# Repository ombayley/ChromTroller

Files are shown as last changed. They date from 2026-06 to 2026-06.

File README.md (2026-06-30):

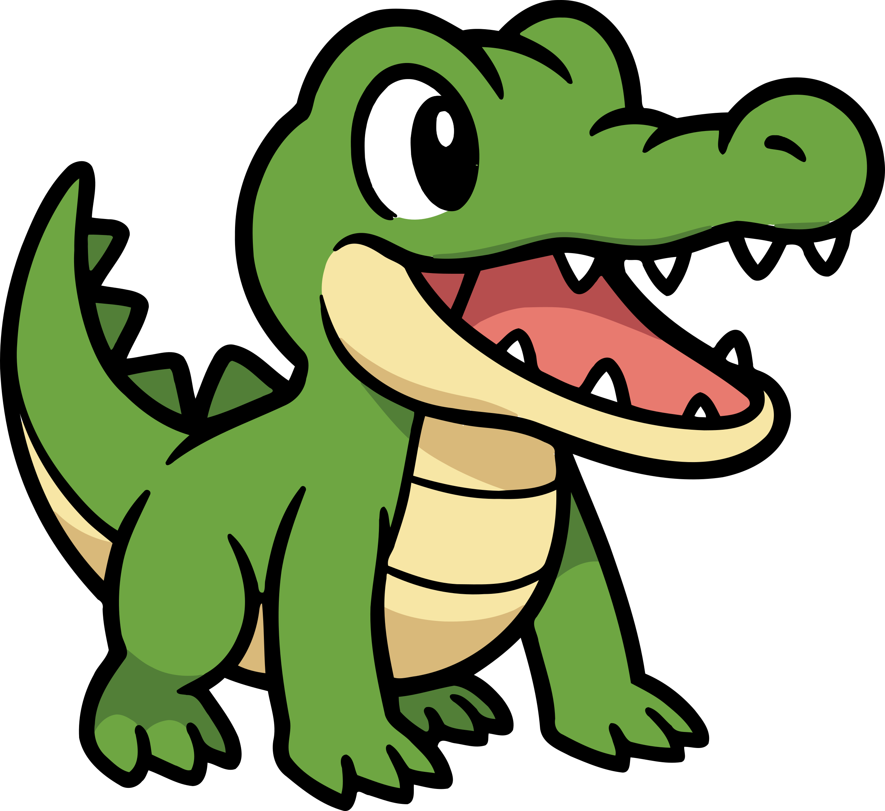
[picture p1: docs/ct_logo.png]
#  ChromTroller

> ***"Pressure makes diamonds"***  
> — *George S. Patton Jr.*
---

## 🧪 Overview
**ChromTroller** (Chromatogram Acquisition Controller) is an automated control‑and‑analysis package that triggers an **Agilent 1290 Infinity II UPLC‑MS** via an **Arduino** and automatically analyzes the resulting chromatographic data.  
It integrates LC/MS hardware (valves, sensors) with a remoteable client–server app and a robust analysis pipeline (MOCCA‑based), making it easy to slot an Agilent UPLC into automated workflows.

ChromTroller was developed to bridge **OpenLab CDS v2.8** (which lacks macro automation) with external experiment controllers (e.g., **RoboChem**) by providing **hardware control**, **data analysis**, and **TCP/IP communication** between PCs.

---

## 📋 Table of Contents

- [Installation](#️installation)
  - [Dependencies](#-dependencies)
  - [Environment Setup](#-environment-setup)
  - [Hardware & Firmware](#-hardware--firmware)
- [Usage](#️usage)
  - [Prepare](#prepare)
  - [Start the Server](#start-the-server)
  - [Configure Settings](#configure-settings)
- [HPLC System Details](#-uplc-system-details)
- [Automation & Connectivity](#-automation--connectivity)
- [Project Structure](#-project-structure-simplified)
- [Architecture](#-architecture)
- [Troubleshooting](#-troubleshooting)
- [Contributing](#contributing)
- [License](#license)
- [Acknowledgements](#acknowledgements)
- [Author](#author)

---

## ⚙️ Installation

### 📦 Dependencies
Before proceeding, make sure you have:

- [**Python 3.8+**](https://www.python.org/downloads/) *(Recommended: Python 3.13)*
- [**Conda**](https://www.anaconda.com/download) *(Recommended: install via Anaconda)*
- [**Git**](https://git-scm.com/downloads)
- **Arduino IDE** from [arduino.cc](https://www.arduino.cc/)
- **Agilent OpenLab CDS v2.8** (instrument control)
- *(Optional)* A Python IDE (e.g. [**PyCharm Community Edition**](https://www.jetbrains.com/pycharm/download/?section=windows))

*Conda helps isolate project dependencies to avoid version conflicts across Python projects.  
Git enables version control and easy updates to the codebase.*

---

### 🧪 Environment Setup
Create and activate the Conda environment from the provided spec:

```bash
conda env create -f .config/ChromTroller_env.yml
conda activate ChromTroller
```

---

### 🧠 Hardware & Firmware
1) **Assemble & wire hardware**  
   Follow the **control box** assembly guide in [`assembly_readme.md`](assembly_readme.md).

2) **Upload the Arduino sketch**  
   - Board: **Arduino Uno R3**  
   - Connect via USB and select the correct **COM** port in the Arduino IDE.  
   - Upload the firmware from `src/arduino_sketches/`.

3) **Supported peripherals**  
   - **VICI** two‑position six‑port switch valve (with micro‑electric actuator & controller)  
   - **OCB350** phase sensor board  
   - Agilent **1290 Infinity II UPLC‑MS**

---

# ▶️ Usage

### Prepare
- Ensure **OpenLab CDS v2.8** is installed and the instrument is available on the **instrument PC**.
- Connect the **Arduino Uno R3** over USB; note the assigned **COM** port.
- Verify valves and sensors are wired and powered.
- Confirm file paths (raw data, results) are accessible by the account running ChromTroller.

### Start the Server
Launch the ChromTroller server on the instrument PC:

```bash
python ChromTroller.py
```

This exposes a **TCP/IP socket** for remote clients (e.g., RoboChem) while handling low‑level device control and data analysis.

### Configure Settings
Copy the example settings and customize for your setup:

```text
src/settings_files/example_settings.json  →  src/settings_files/settings.json
```

Key fields to adjust:
- **Hardware**: Arduino **COM** port, valve positions, timeouts  
- **Analysis**: Peak detection/integration parameters, baseline correction, wavelength ranges  
- **Paths**: Project directories, file naming, raw data / results locations  
- **Targets**: Retention times and tolerances for peak assignment

---

## 🔬 UPLC System Details

**Instrument:** Agilent 1290 Infinity II series with:  
- **High Speed Binary Pump** (G7120A)  
- **Vial Sampler** (G7129B)  
- **Thermostated Column Compartment** (G7116B)  
- **Diode Array Detector** (G7117B, DAD)  
- **InfinityLab LC/MSD XT** Single Quadrupole detector (G6135C)

**Injection hardware:** External **VICI** two‑position six‑port valve with a **1.0 µL** stainless‑steel loop (≈ 90 mm × 0.12 mm). Effective injected volume ≈ **1.4 µL** due to additional valve dead volume.

---

## 🔗 Automation & Connectivity

**OpenLab CDS v2.8** controls the UPLC but lacks a macro language for automation. **ChromTroller** fills this gap by providing:

1. **Hardware control** (valve actuation, ERI digital I/O, phase sensor).  
2. **Data analysis** (see next section).  
3. **Intersystem communication** (TCP/IP sockets).

### Sample Injection & Triggering
- A VICI valve is installed **between the vial sampler and column**.  
- **Position “load”** fills the loop from the external process at low pressure; **position “inject”** places the loop inline for analysis.  
- The **VICI actuator** is driven from the control box; the **UPLC acquisition** is triggered via **Agilent ERI** digital input.  
- In OpenLab, a **Sample Prep** method is configured to **wait for an external trigger** (e.g., “pin 1”). Runs can be queued and started only when the **START REQUEST** signal is received from ChromTroller/Arduino.

This ensures **tight timing** between valve switching and acquisition start, improving retention‑time reproducibility and peak shapes.

### Serial Protocol (to Control Box)
Commands are human‑readable:
- **Set:** `Sx=y` (no response unless specified)
- **Read:** `Rx` (always returns value)

Key variables include: valve position (`5`, 0=A / 1=B), **START REQUEST** (`6`), **STOP** (`7`), **READY** (`8`), **phase sensor** (`9–10`), and ERI **state lines** (`11–13`). See [`assembly_readme.md`](assembly_readme.md) for the full table.

---

## 🧠 Data Analysis

ChromTroller includes a processing pipeline based on the [**MOCCA**](https://github.com/Bayer-Group/MOCCA) package from the BAYER group.
This analysis system parses the raw files, automatically processes the chromatograms contained within , and returns tidy results (e.g., a pandas DataFrame). Operations include:
- file parsing and dimensional reduction  
- baselining and peak picking  
- deconvolution, integration, and quantification  
- identity assignment and error analysis

This enables multi‑wavelength chromatograms to be consumed by external platforms (e.g., RoboChem) as simple peak integrals.

---

## 📂 Project Structure (Simplified)

```
ChromTroller/
├── .config/                 # Conda environment specs
├── docs/                    # Documentation & diagrams
├── reference_spectra/       # Reference spectra for analysis
├── reference_spectra_db/    # Spectra database
├── results/                 # Latest analysis results
├── run_logs/                # Runtime logs
├── saved_results/           # Archived analysis runs
├── src/                     # Source code
│   ├── ct_components/       # Core components
│   │   ├── devices/         # Device interfaces
│   │   └── mocca2/          # MOCCA-based analysis
│   ├── arduino_sketches/    # Arduino firmware
│   └── settings_files/      # JSON configuration
├── ChromTroller.py          # Entry point (server)
├── assembly_readme.md       # Control box build guide
└── README.md
```

---

## 🧱 Architecture

```mermaid
graph TD;
    Client[Client Application] <-->|TCP/IP Socket| Server[ChromTroller Server]
    Server <--> Controller[LCMS Controller]
    Controller <-->|Serial| Arduino[Control Box]
    Arduino -->|I/O| LCMS[Agilent LC/MS]
    Arduino -->|I/O| Valve[VICI Switch Valve]
    Controller --> Monitor[System Monitor]
    Controller --> Analyzer[Data Analyzer]
```

---

## 🛠️ Troubleshooting

**Connection issues**
- Confirm the **COM** port in `settings.json` matches Device Manager.
- Ensure **Arduino drivers** are installed and the board is detected.
- Close any program using the serial port (Arduino Serial Monitor, etc.).

**Acquisition/trigger issues**
- Verify the OpenLab **Sample Prep** method waits for the correct **ERI pin**.
- Check grounds/common reference between ERI and control box.
- Confirm valve position changes acknowledge back to the host.

**Analysis errors**
- Verify raw data paths and filenames match LC/MS export settings.
- Check analysis parameters (peak detection, baselining) against your method.
- Ensure **reference spectra** exist and are correctly formatted.

---

## Contributing
Contributions are welcome—please open a Pull Request with a clear description of your changes.

---

## License
This project is licensed under the **GNU General Public License (GPL)**. See the `LICENSE` file for details.
The GPL License is a copyleft license, that requires any derivative work to also be released under the GPL License.
This means any derivative software that uses this code remains open-source and freely available to the public.

---

## Acknowledgements
- **Bayer Group** for the **MOCCA** package
- **Agilent Technologies** for instrument support

---

## Author
**Olly Bayley** — *Noël Research Group, 2024* — <o.m.bayley@uva.nl>

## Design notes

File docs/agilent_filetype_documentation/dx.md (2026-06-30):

.dx files have been introduced in the latest version of Agilent's OpenLab CDS software and have no official documentation fo rhtier build.
These files are compressed archives and can be extracted with pythons zipfile module.
within these files are:
```
MSData/MSScan.xsd
_rels/.rels
[Content_Types].xml
MSData/Contents.xml
MSData/Devices.xml
2d4ed283-e283-470a-985f-c8650b5b92ba.UV
2d4ed283-e283-470a-985f-c8650b5b92ba.UVD
_rels/2d4ed283-e283-470a-985f-c8650b5b92ba.UV.rels
1aff4f0e-4b5d-4e62-a6b1-08e206e7c1a8.IT
...
4bf708a6-c0b3-4d70-87d3-de375632a9f9.IT
a94b341b-8600-47a2-aad6-641f0e04fb1f.CH
742c0a8e-994d-4588-a6a1-122438f1cbba.grd
2ce53aef-85cd-485f-84b8-cc1849d7ffb5.grd
MSData/MSTS.xml
injection.acmd

```

the .xml and .xsd files contain metdatadata on the aquired MS data which is stored seperately in the .MSPeak.bin and .MSScan.bin files.
the .UV files contain the 3D UV data of the chromatogram across wavelengths.
the .UVD files contain UV data of the chromatogram at a given wavelength.
the .IT files contain all the info of the hardware (temperatures, currents, pressures, etc...) but are not marked

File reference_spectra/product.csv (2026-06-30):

Wavelength | Absorbance
190 | 1774.6708765626
192 | 2121.88488990068
194 | 2375.61110407114
196 | 2525.90990811586
198 | 2598.21579605341
200 | 2442.80843436718
202 | 2021.09553664923
204 | 1645.53967863321
206 | 1429.40447479486
208 | 1363.24195563793
210 | 1403.28350663185
212 | 1500.91804563999
214 | 1630.83799928427
216 | 1786.28665208817
218 | 1962.86478638649
220 | 2138.08164000511
222 | 2239.62888866663
224 | 2217.36065298319
226 | 2048.58722537756
228 | 1695.46644389629
230 | 1189.98455256224
232 | 750.307559967041
234 | 438.227631151676
236 | 237.149432301521
238 | 127.045348286629
240 | 70.9682479500771
242 | 48.0436086654663
244 | 40.6952500343323
246 | 41.3642153143883
248 | 46.7967465519905
250 | 55.819496512413
252 | 68.8679218292236
254 | 85.2684676647186
256 | 106.099911034107
258 | 131.305046379566
260 | 159.867562353611
262 | 192.783609032631
264 | 229.336336255074
266 | 267.788626253605
268 | 307.406671345234
270 | 344.527617096901
272 | 379.161648452282
274 | 408.477559685707
276 | 419.78008300066
278 | 404.235295951366
280 | 376.990087330341
282 | 346.709810197353
284 | 287.109293043613
286 | 192.304745316505
288 | 103.096276521683
290 | 46.9016432762146
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

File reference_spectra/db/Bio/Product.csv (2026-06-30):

wavelength | absorbance
200.11 | 1652248.317841719
201.35 | 1518626.7446007319
202.59 | 1409723.0336609771
203.83 | 1345719.0684464027
205.07 | 1315815.34410467
206.32 | 1335642.3990441423
207.56 | 1374566.634268652
208.8 | 1386294.327582356
210.04 | 1355498.8827266581
211.29 | 1222791.7088032707
212.53 | 1013564.1721269303
213.77 | 807294.566148546
215.02 | 659859.0798216447
216.26 | 576460.3337595625
217.51 | 544372.7893987078
218.75 | 547171.3919146114
220.0 | 573304.3286487326
221.24 | 618176.3197648147
222.49 | 681218.3270397268
223.73 | 762177.7880653779
224.98 | 859045.5369520837
226.23 | 972766.143825681
227.47 | 1102406.9129294488
228.72 | 1246440.3125703991
229.97 | 1406488.0750157111
231.21 | 1577238.971505137
232.46 | 1768913.1941411793
233.71 | 1986559.759761608
234.96 | 2249590.8561227727
236.21 | 2642367.3698617904
237.46 | 3602018.0435978174
238.7 | 3995753.818190497
239.95 | 3997355.226358936
241.2 | 3998559.2014973755
242.45 | 3999506.0577509594
243.7 | 4000112.0859490363
244.95 | 4000691.566861483
246.2 | 4001020.8119115396
247.45 | 3101606.0585562405
248.7 | 2536995.9973240388
249.96 | 2274294.6582513503
251.21 | 2089659.7870108662
252.46 | 1948915.9306409345
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

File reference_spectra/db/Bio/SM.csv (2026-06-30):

wavelength | absorbance
200.11 | 1600300.5390176924
201.35 | 1467923.8272445255
202.59 | 1358122.9078490594
203.83 | 1264765.0566162318
205.07 | 1198447.4764689966
206.32 | 1148110.328346475
207.56 | 1103487.1848139924
208.8 | 1047433.1408762458
210.04 | 980121.6066031756
211.29 | 904700.4083839374
212.53 | 830516.1944663429
213.77 | 764927.9947905622
215.02 | 709102.8668123287
216.26 | 663878.5572056993
217.51 | 626569.1597787745
218.75 | 593176.0468914836
220.0 | 563295.510730236
221.24 | 535586.7281283623
222.49 | 510241.09102563275
223.73 | 489444.80710435455
224.98 | 474612.7214355952
226.23 | 466878.62356072484
227.47 | 466052.06095353345
228.72 | 472449.9139672729
229.97 | 484896.51980854647
231.21 | 503562.3369430287
232.46 | 528277.3686688787
233.71 | 559442.2327329945
234.96 | 597356.5471626982
236.21 | 642226.5448825333
237.46 | 695181.5851742572
238.7 | 757515.7183649899
239.95 | 829415.5770351929
241.2 | 911014.2212274143
242.45 | 1000763.6215320051
243.7 | 1097315.8393677927
244.95 | 1198720.1136332257
246.2 | 1301654.7210051392
247.45 | 1404777.2871813453
248.7 | 1505385.9711170834
249.96 | 1601488.9095195592
251.21 | 1690701.1976298431
252.46 | 1772766.4592760615
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

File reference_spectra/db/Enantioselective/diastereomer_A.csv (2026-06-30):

wavelength | absorbance
220 | 32929570.901172925
221 | 30251595.791809924
222 | 27583494.818783533
223 | 24920838.862576447
224 | 22281363.59773891
225 | 19708573.553817563
226 | 17133784.992652226
227 | 14899457.244885486
228 | 12923490.142887829
229 | 11244676.08669167
230 | 9881621.35323525
231 | 8785643.164572146
232 | 8050352.479092054
233 | 7579730.6301938
234 | 7338509.315241723
235 | 7293871.174475303
236 | 7420382.117641768
237 | 7687797.818173384
238 | 8076449.919397999
239 | 8601397.975483036
240 | 9191594.24214197
241 | 9852788.080277443
242 | 10609693.603409687
243 | 11362795.19895376
244 | 12133063.595042046
245 | 12906321.155902734
246 | 13710361.519871686
247 | 14441107.555550737
248 | 15116374.461307991
249 | 15736769.00143304
250 | 16205210.952189613
251 | 16533867.067726329
252 | 16719365.25556228
253 | 16747056.601230377
254 | 16642112.627814714
255 | 16402371.820754118
256 | 16056131.942559408
257 | 15541650.596207984
258 | 14871824.327734014
259 | 13980749.864755994
260 | 12775419.005677002
261 | 11405935.32215776
262 | 9892922.952019326
263 | 8259552.939423117
264 | 6790920.935680518
265 | 5414517.3507355
266 | 4314561.486903784
267 | 3374841.152450751
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

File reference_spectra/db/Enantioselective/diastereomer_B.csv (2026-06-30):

wavelength | absorbance
220 | 146213297.49883443
221 | 133537360.24735336
222 | 121009732.8859455
223 | 108921893.9741113
224 | 97455809.49136508
225 | 86720889.4986895
226 | 76273984.969608
227 | 67300330.93427262
228 | 59308084.82672971
229 | 52365329.69812251
230 | 46520327.205076724
231 | 41572457.86271553
232 | 38014100.236981496
233 | 35493444.15485315
234 | 33922945.50170027
235 | 33182879.313989375
236 | 33248012.0135607
237 | 33972025.61092472
238 | 35281486.149522275
239 | 37231809.69035273
240 | 39559161.97460105
241 | 42280367.271799624
242 | 45509599.48347034
243 | 48818600.777864635
244 | 52293686.93691794
245 | 55869603.75952901
246 | 59694385.30479761
247 | 63301515.31915083
248 | 66795605.77397436
249 | 70212349.72042921
250 | 73009906.00948425
251 | 75197434.31494759
252 | 76714577.76822823
253 | 77377584.36839387
254 | 77344139.10675211
255 | 76682552.50434124
256 | 75537485.23177217
257 | 73702112.31727603
258 | 71129598.20131448
259 | 67416444.14116977
260 | 62026025.24018093
261 | 55614213.38144096
262 | 48340234.38580763
263 | 40372242.82207139
264 | 33161537.512689497
265 | 26366671.987668518
266 | 20905616.22336069
267 | 16223439.586571513
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

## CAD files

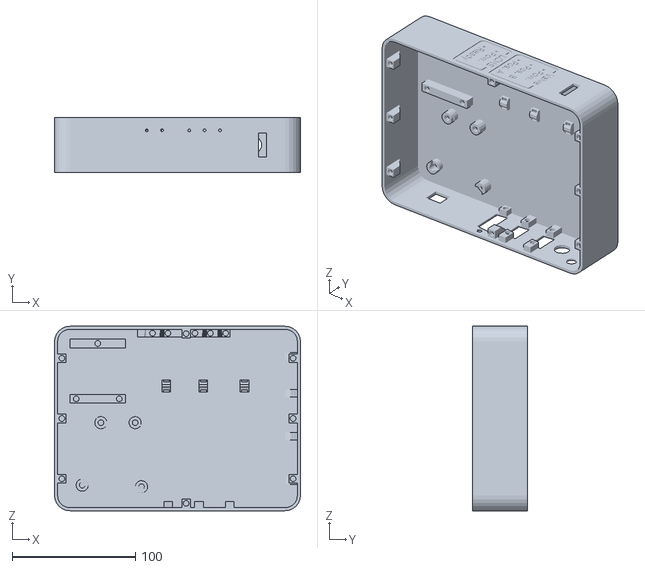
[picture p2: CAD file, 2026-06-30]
src/hrd_control/devices/arduino_controller/stl/LC_ENC.stl
200.0 x 45.0 x 150.0

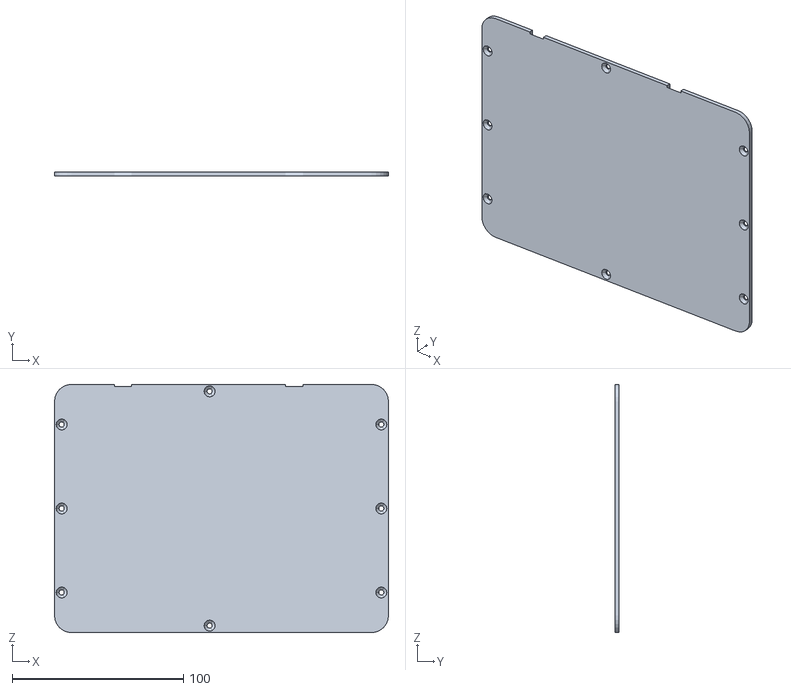
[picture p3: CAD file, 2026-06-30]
src/hrd_control/devices/arduino_controller/stl/LC_ENCL.stl
194.9 x 2.50 x 144.9

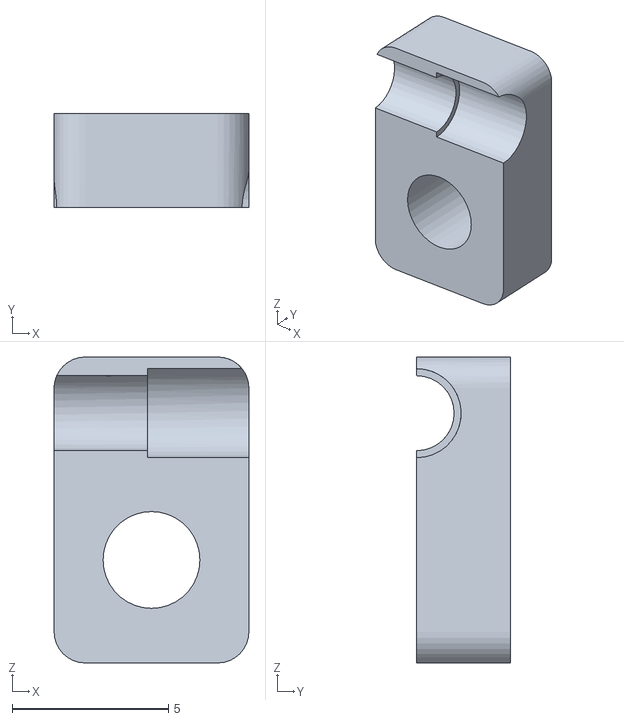
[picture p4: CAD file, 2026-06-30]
src/hrd_control/devices/arduino_controller/stl/LED_clamp.stl
6.24 x 3.00 x 9.80

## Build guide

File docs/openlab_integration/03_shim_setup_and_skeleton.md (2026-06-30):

# OpenLab Shim: Setup, Concepts, and Skeleton

This guide gets you from nothing to a running **C# shim** that drives the Agilent 1290 via
the OpenLab Acquisition SDK, controlled from ChromTroller's normal **64-bit Python**. It
covers environment setup, how the pieces fit together, and the full skeleton code.

**The skeleton files (all the code) live alongside this guide:**

```
docs/openlab_integration/shim/
  OpenLabShim/
    OpenLabShim.csproj      # x86 / net48 build definition + SDK references
    Program.cs              # the shim: connect, take control, dispatch loop, events
    shim.config.json        # discovered values (IDs, valve firmware cmds, param map)
  python/
    openlab_device.py       # CT-side client (default + whitelist policy lives here)
    example_usage.py        # minimal end-to-end demo
```

- C# shim: [Program.cs](shim/OpenLabShim/Program.cs), [OpenLabShim.csproj](shim/OpenLabShim/OpenLabShim.csproj), [shim.config.json](shim/OpenLabShim/shim.config.json)
- Python client: [openlab_device.py](shim/python/openlab_device.py), [example_usage.py](shim/python/example_usage.py)

---

## 1. How it works (conceptually)

```
RoboChem client ──TCP──► ChromTroller (64-bit Python)
                            │  stdin/stdout line protocol
                            ▼
                       OpenLabShim.exe (x86 .NET 4.8)  ← the ONLY 32-bit component
                            │  in-process SDK calls
                            ▼
                       OpenLab Acquisition ──► 1290 Infinity II
```

**Why a separate process at all.** The OpenLab Acquisition assemblies are **x86 /
.NET Framework**. Loading them *in-process* would force ChromTroller itself to be 32-bit
(breaking MOCCA/numpy). Putting them in a **separate process** decouples bitness: a 64-bit
and a 32-bit process coexist fine and just exchange text. The shim is the same architectural
role the Arduino plays today — an out-of-process device CT talks to over a line protocol —
only it calls the real SDK instead of toggling pins.

**Why it's persistent.** Connecting to the instrument is a slow, stateful handshake
(authenticate → `EstablishConnection` → wait for `AppInitialized` + `InstrumentStateChange`)
and run progress arrives as **events**. So the shim connects **once** at startup, takes
control, then loops reading commands. One process, many commands — exactly like opening a
serial port once.

**Two output channels on one pipe.** Every command gets a synchronous `OK ...` / `ERR ...`
reply. Run progress is *unsolicited*: `EVENT ...` lines during the run and a final
`RESULT <id> <path>`. The Python client's reader thread classifies the two — replies go to a
response queue the command call blocks on; events go to a callback CT uses to stream status
and detect completion.

**Where policy lives.** ChromTroller owns the *policy* — the method library, defaults, which
overrides are allowed and their ranges (the `default + whitelist` design). The shim owns the
*SDK mapping* — module hashkeys, the valve's firmware string, which property id a logical
param maps to. The client only ever uses logical names; instrument internals never leak out.

---

## 2. The line protocol

| Direction | Message | Meaning |
|---|---|---|
| CT → shim | `PING` | liveness check → `OK pong` |
| CT → shim | `SET_VALVE load` / `SET_VALVE inject` | switch built-in valve (firmware command) |
| CT → shim | `SET_PARAM flow=0.5` | stage a whitelisted deep method override |
| CT → shim | `START_RUN {json}` | submit a run (json: method, processing, vial, injvol, result) |
| CT → shim | `ABORT` | abort current run |
| CT → shim | `STATUS` | current instrument state |
| CT → shim | `QUIT` | disconnect and exit |
| shim → CT | `READY` | connected + control taken (emitted once at startup) |
| shim → CT | `OK <payload>` / `ERR <msg>` | synchronous reply to the last command |
| shim → CT | `EVENT STATE <state>` / `EVENT RUN <id> <status>` | async progress |
| shim → CT | `RESULT <id> <path>` | run complete; `.dx` result path |
| shim → CT | `FATAL <msg>` | startup/connection failure |

`START_RUN` uses a JSON payload (not space-delimited tokens) so method paths with spaces
escape cleanly.

---

## 3. Environment setup

### 3.1 Prerequisites (on the Acquisition PC / AIC)

- [ ] OpenLab CDS 2.8 **Acquisition** installed; the 1290 is configured and controllable
      from the OpenLab UI.
- [ ] **OpenLab SDK entitlement licensed** (Control Panel → Administration → Licenses).
      Without it `EstablishConnection` fails.
- [ ] You can read the **Instrument GUID** and **Project GUID** from the OpenLab Control
      Panel (used in `shim.config.json`).
- [ ] A service account (login/domain/password) the shim authenticates as.
- [ ] **Bench-discovery values** to fill the config: the column-valve firmware commands for
      each position, and the module-name/property-id for any deep params you expose
      (`flow`, `col_temp`). These come from the discovery script (next deliverable) / Lab
      Advisor — do not guess them.

### 3.2 C# build environment

- Install **Visual Studio 2022** with the **.NET desktop development** workload, *or* the
  **.NET Framework 4.8 Developer Pack** + .NET SDK (for `dotnet build`).
- The project targets **`net48`** and **`PlatformTarget=x86`** — both are mandatory and
  already set in [OpenLabShim.csproj](shim/OpenLabShim/OpenLabShim.csproj).
- Fix the assembly `HintPath`s in the csproj to match your install:
  - The two `Agilent.OpenLAB.Acquisition.*` assemblies are in the **32-bit GAC**. List the
    folder to get the exact version segment:
    ```bat
    dir "C:\Windows\Microsoft.NET\assembly\GAC_32\Agilent.OpenLAB.Acquisition.AutomationInstrument"
    ```
  - `Agilent.OpenLab.SharedServices*` are under
    `C:\Program Files (x86)\Agilent Technologies\OpenLab Services\Common\` and
    `...\OpenLab Acquisition\`.
- Build (x86):
  ```bat
  dotnet build docs\openlab_integration\shim\OpenLabShim\OpenLabShim.csproj -c Release
  ```
  or build the project in Visual Studio with the **x86** configuration. Output:
  `OpenLabShim.exe`.

> The build does **not** copy the Agilent DLLs locally (`<Private>false</Private>`). At
> runtime they (and their many dependencies) are resolved from the install dirs by the
> `AssemblyResolve` handler in `Program.cs`. Keep the exe on the AIC where those dirs exist.

### 3.3 Python environment

**No new environment.** This is the whole point — ChromTroller's existing **64-bit** env is
untouched. There is no pythonnet, no 32-bit Python, no second conda env.

1. Copy [openlab_device.py](shim/python/openlab_device.py) into
   `src/hrd_control/devices/` when you integrate (it has no third-party dependencies —
   stdlib only).
2. Edit the **policy block** at the top of `openlab_device.py` — `METHODS`, `DEFAULTS`,
   `OVERRIDE_WHITELIST`, `PARAM_WHITELIST` — to match your methods and the knobs you want
   the client to control. Keep the `PARAM_WHITELIST` keys in sync with the shim config's
   `ParamMap`.

### 3.4 Configure the shim

Edit [shim.config.json](shim/OpenLabShim/shim.config.json):

- `Login` / `Domain` / `Password` — the service account. **Do not commit a real password**;
  inject it at deploy time from a secret.
- `InstrumentId` / `ProjectId` — GUIDs from Control Panel.
- `ValveModuleMatch` — a substring of the column-compartment module name (e.g. `"Column Comp"`).
- `ValveFirmware.load` / `.inject` — the discovered firmware command strings.
- `ParamMap` — for each whitelisted deep param, the module-name substring + resource
  property id from discovery.

---

## 4. First run / smoke test

1. Build the shim (§3.2) and fill the config (§3.4).
2. Quick manual check straight from a terminal (type commands, watch replies):
   ```bat
   OpenLabShim.exe shim.config.json
   READY
   PING
   OK pong
   STATUS
   OK Idle
   QUIT
   OK bye
   ```
   If you see `FATAL ...` instead of `READY`, the connection failed — check the SDK
   license, the GUIDs, and that you're on the AIC.
3. End-to-end from Python: edit the paths at the bottom of
   [example_usage.py](shim/python/example_usage.py) and run it in your 64-bit env.
   It does: `set_valve("load")` → `submit_run(...)` → waits for the `RESULT` event.

---

## 5. Integrating into ChromTroller

The shim/client mirror the existing device abstraction, so integration is mostly swapping
the transport:

- Add `src/hrd_control/devices/openlab_device.py` (the client).
- In [ct_controller.py](../../src/hrd_control/ct_controller.py):
  - construct `OpenLabDevice(exe, config, on_event=...)` and `start()` it where the
    Arduino/`LCMSDevice` is set up today;
  - `run_sample_acquisition()` becomes: `set_valve("load")` → (await loop fill) →
    `submit_run(...)` → await the `RESULT` event → hand the `.dx` to
    [ct_analyser.py](../../src/analysis/ct_analyser.py);
  - route `on_event` status lines back to the TCP client.
- Retire the Arduino trigger path (`send_start_request`, ERI reads). Keep the Arduino only
  if the OCB350 phase sensor is still wired through it.
- The file-watch in [ct_monitor.py](../../src/file_mgmnt/ct_monitor.py) can be simplified or
  removed — `RESULT` carries the result path directly.

---

## 6. Known TODOs in the skeleton (confirm against your installed assembly)

These are member names taken from the SDK reference guide; verify when you build (search
`TODO confirm` in `Program.cs`):

- `Connection.TicketContainer.Ticket` — exact accessor for the security ticket string
  (Programmer's Guide, SharedServices section).
- The module name property (`.Name` vs `.DisplayName`) on `ic.Modules`.
- `RunSubmissionResult.RunId` and `RunRecordUpdate.ResultFilePath` field names.
- Whether deep overrides need the `Load → Set → SaveAs` path (used here) or persist into a
  submitted run without the save-as — verify on the bench.
- For **external** injection, whether `InjectionVolume` is meaningful or governed by the
  loop (`InjectionSource.SupportsUseMethodVolume`).

---

*Prerequisite for filling the config: the bench discovery script (valve firmware commands,
module/property ids, instrument/project GUIDs). See the migration report,
[02_chromtroller_migration_report.md](02_chromtroller_migration_report.md), for the overall
plan and phasing.*

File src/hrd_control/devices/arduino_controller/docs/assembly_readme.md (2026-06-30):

# ChromTroller Control Box — Assembly Guide

> Hardware build notes for the ChromTroller valve/trigger controller

---

## 📦 Overview

The **ChromTroller control box** is a small microcontroller-based module that:
- Drives a **VICI micro‑electric actuator** to toggle a **two‑position, six‑port** switching valve for sample injection.
- Issues and reads **digital I/O** signals to/from the **Agilent ERI (Enhanced Remote Interface)** on compatible 1290 Infinity II modules to start/stop and monitor runs.
- Optionally interfaces with an **OCB350 phase sensor** for flow-phase monitoring.
- Provides a **fused power path** for the actuator and a front‑panel **power switch**.
- Communicates with the host PC via **USB serial** (Arduino Uno R3).

This ensures the physical injection is **time‑aligned** with UPLC data acquisition, giving reproducible retention times.

---

## 🧰 Bill of Materials (BOM)

| Component | Qty | Supplier | Price (ea) | Part No. |
|---|---:|---|---:|---|
| Arduino Uno R3 | 1 | Conrad | € 16.17 | 191789 |
| Power switch | 1 | Conrad | € 2.30 | 1588060 |
| DC barrel connector 5.5 mm / 2.5 mm | 5 | Conrad | € 1.29 | 1582328 |
| Fuse holder (box) | 1 | Conrad | € 1.49 | 533769 |
| 10 A fuse 5×20 mm (pack of 10) | 1 | ESKA | € 1.49 | 522.627 |
| D‑Sub 9 female | 1 | Conrad | € 0.56 | 1924663‑8J |
| D‑Sub 9 male | 1 | Conrad | € 0.35 | 1303906‑8J |
| D‑Sub 15 female | 1 | Conrad | € 0.64 | 1586473‑8J |
| Module box (print) | 1 | — | — | `LC_ENC.stl`  |
| Module box lid (print) | 1 | — | — | `LC_ENCL.stl` |

*Prices as purchased; may change.*

You will also need hookup wire, crimp pins/hoods for D‑Sub connectors, stand‑offs/screws for the Arduino, and heat‑shrink.

---

## 🧱 Enclosure & Front Panel

- 3D‑print `LC_ENC.stl` (box) and `LC_ENCL.stl` (lid).
- Front panel typical cut‑outs: **power switch**, **fuse holder**, **barrel DC jack(s)**, and **status LEDs** (optional).
- Rear panel typical cut‑outs: **D‑Sub‑15** (ERI), **D‑Sub‑9** (valve/aux), and **USB‑B** (Arduino).

> Keep high‑current actuator wiring physically separated from logic lines to reduce noise. Tie grounds at a single star point.

---

## ⚡ Power & Safety

- The actuator is powered via the fused DC input (**5×20 mm, 10 A**). Size the fuse for your actuator’s supply and inrush.
- The **Arduino** is powered via **USB** from the PC. If you power it from the actuator supply, use a regulated 5 V rail and common ground.
- Use **strain relief** for all external cables.
- **Always disconnect power** before rewiring. Verify polarity and fuse rating before first power‑up.

> **Disclaimer:** You are responsible for safe mains/DC wiring and compliance with your local regulations.

---

## 🔌 Interfaces (High‑level)

- **VICI actuator controller:** digital input for **Position A/B** (check your controller’s manual). The control box outputs logic‑level signals from the Arduino to the actuator controller input. 
- **Agilent ERI (Enhanced Remote Interface):** provides digital **Start/Ready/Prepare** lines. The exact pinout **depends on the module**; refer to the Agilent ERI documentation for your model. In practice, a **Sample Prep** method in **OpenLab CDS v2.8** is configured to await a rising edge on a chosen input line (commonly “pin 1”) before starting acquisition.
- **Phase sensor (OCB350):** connect signal and supply per the sensor datasheet. The Arduino reads the sensor for phase monitoring and calibration.

> For detailed wiring schematics and mechanical drawings, see the figures referenced as *Figure S1.66–S1.67* in your documentation folder.

---

## 🧪 Assembly Steps

1. **Prep enclosure**: Deburr prints, test‑fit all panels and connectors.
2. **Mount hardware**: Install the power switch, fuse holder, barrel jack(s), D‑Sub connectors, and Arduino with stand‑offs.
3. **Power wiring**: Wire DC jack → fuse → power switch → actuator supply rail. Keep logic ground connected to the actuator ground at a **single star point**.
4. **ERI harness**: Crimp a D‑Sub‑15 harness to the ERI cable. Map **Start**, **Ready**, **Prepare**, and **GND** per **Agilent ERI** manual for the modules you use.
5. **Actuator harness**: Wire Arduino output pin(s) to actuator controller inputs (through appropriate series resistors or driver stage if required by your actuator). Share **GND**.
6. **Phase sensor**: Provide the sensor supply (per datasheet). Connect signal output to an Arduino digital/analog pin specified in firmware.
7. **Label** all external connectors, add strain relief, close the lid.

---

## 🔧 Firmware & Serial Protocol

Flash the **Arduino Uno R3** with the ChromTroller control firmware (see repository). Connect via **USB serial**.
Commands use human‑readable syntax:

- **Set/Write:** `Sx=y`  
  *Sets variable `x` to value `y` (type depends on variable).*
- **Get/Read:** `Rx`  
  *Reads variable `x` and prints its value.*

> Unless specified, `Sx=y` does not print a response. `Rx` always prints a value.

### Variables

| No. | Access | Type | Description |
|---:|:---:|:---|:---|
| 1 | R/W | `STRING[20]` | Device identifier |
| 2 | R | `INT[0–254]` | Error register `x-y` (type‑value). Resets on read |
| 3 | CMD | `NONE` | Save defaults |
| 4 | CMD | `NONE` | Factory reset |
| 5 | R/W | `INT[0–1]` | **Valve position** (0=A, 1=B). Sends acknowledge when done |
| 6 | CMD | `NONE` | Send **START REQUEST** to UPLC |
| 7 | CMD | `NONE` | Send **STOP** |
| 8 | R | `INT[0–1]` | Read **READY** from UPLC |
| 9 | CMD | `NONE` | **Calibrate** phase sensor |
|10 | R | `INT[0–3]` | Read phase sensor output |
|11 | R | `INT[0–1]` | Read LCMS **power state** |
|12 | R | `INT[0–1]` | Read UPLC **start** signal |
|13 | R | `INT[0–1]` | Read UPLC **prepare** signal |

*If the value type is `NONE`, the equal sign is still required (e.g., `S6=`).*

### Quick Test (Arduino IDE Serial Monitor)

1. Set the valve to A/B: `S5=0` → wait for ack, then `S5=1`  
2. Read READY state: `R8`  
3. Trigger a run (with OpenLab **Sample Prep** method waiting): `S6=`  
4. Stop signal (if configured): `S7=`  
5. Phase sensor: `S9=` to calibrate, then `R10` to read

---

## 🧪 Commissioning with OpenLab CDS v2.8

1. Create/modify a **Sample Prep** method that **waits for external trigger** (e.g., *pin 1* on ERI).  
2. On the instrument PC, start **ChromTroller** and connect the control box via USB.
3. **Queue** runs in OpenLab. They will remain pending until a **START REQUEST** is received.  
4. From ChromTroller (or manual serial), coordinate:
   - Set valve to *LOAD*; fill loop from RoboChem.  
   - Switch to *INJECT* and **immediately** issue `S6=` to start acquisition.  
   - Monitor **READY/START/PREPARE** lines to verify timing.  

This coupling ensures **1.4 µL** effective injection (1 µL loop + valve dead volume) is time‑aligned with data acquisition.

---

## 📎 Notes

- Effective injection volume is ~**1.4 µL** due to loop (1.0 µL, 90 mm × 0.12 mm) plus valve dead volume.
- Keep cable runs short and shielded where possible; reference grounds carefully.
- For ERI pin mapping, **always** consult your module’s manual.

---

## 📄 Figures & Files

- Controller photos & wiring: *Figure S1.67*
- ERI I/O overview: *Figure S1.66*
- Valve sampling/injection: *Figure S1.65*
- General UPLC connectivity: *Figure S1.64*

STLs: `LC_ENC.stl`, `LC_ENCL.stl` (see `docs/` or `hardware/` folder in repo)

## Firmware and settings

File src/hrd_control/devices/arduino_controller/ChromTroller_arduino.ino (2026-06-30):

/*
 --- Arduino controller for the NRG LCMS connected to RoboChem ---

 Serial Communication:
   Sx=y
   Set variable x to value y. Variable number are integer, values are signed floating point.
   Rx
   Read variable x and print its value to serial.

 Variable list:
   number | acccess     | type        | description
   -------|-------------|-------------|--------------------------
    0     | RESERVED    |             | Serial.parseInt returns 0 on error.
    1     | READ/WRITE  | STRING [20] | Device identifier.
    2     | READ_ONLY   | INT-INT     | Error register 'x-y' x = error type, y = error value. Is reset upon reading.
    3     | COMMAND     | NONE        | Save defaults.
    4     | COMMAND     | NONE        | Factory Reset.
    5     | READ/WRITE  | INT[0-1]    | Valve position. Sends acknowledge signal when done. (0=A, 1=B) 
    6     | READ/WRITE  | INT[0-1]    | Send  'START REQUEST' [ERI Remote Pin #1]. Active = Low.  Request to start injection cycle. Receiver is the autosampler.
    7     | COMMAND     | NONE        | Send  'STOP'          [ERI Remote Pin #2]. Active = Low.  Request to reach system ready state as soon as possible. Receiver is any module performing run-time_of_inj controlled activities.
    8     | READ_ONLY   | INT[1]      | Read  'READY'         [ERI Remote Pin #3]. Active = high. Read system status to check if it is ready for next analysis. TODO have constant monitor to check if achieved and reset upon submit
    9     | COMMAND     | NONE        | Send 'Calibrate' command to phase sensor
    10    | READ_ONLY   | FLOAT       | Read phase sensor output
    11    | READ_ONLY   | FLOAT       | Read power state of LCMS
    12    | READ_ONLY   | FLOAT       | Read start signal from the LCMS
    13    | READ_ONLY   | FLOAT       | Read prepare signal from the LCMS
  
 Error codes:
   type  |  description | value
   ------|--------------|--------------
   0     | No error     | Undefined
   1     | Serial error | Variable number which gave the issue
   2     | Other error  | TODO


 Hardware connections (Arduino nano board):
   Agilent Infinity 1290 II UPLC-MS
   Vici Switch-Valve Control Module
   OCB350 phase sensor board


External Device Pinouts:
  Agilent ERI Remote pinout used for the Infinity 1290 II :
    Pin    | Function       | Color         | Connected   | Active State
    -------|----------------|---------------|-------------|---------------
    1      | Start Request  | White         | YES - 2     | LOW
    2      | Stop           | Brown         | YES - 3     | LOW
    3      | Ready          | Green         | YES - 4     | HIGH
    4      | Power On       | Yellow        | YES - 5     | HIGH
    5      | Not Used       | Grey          | NO          | LOW
    6      | Shut Down      | Pink          | YES - 6     | LOW
    7      | Start          | Blue          | YES - 7     | LOW
    8      | Prepare        | Red           | YES - 8     | LOW
    9      | 1Wire Data     | Black         | NO          | -
    10     | Digital Ground | Violet        | YES - GND   | -
    11     | +5V ERI out    | Grey-Pink     | NO          | -
    12     | PGND           | Red-Blue      | NO          | -
    13     | PGND           | White-Green   | NO          | -
    14     | +24V ERI out   | Brown-Green   | NO          | -
    15     | +24V ERI out   | White-Yellow  | NO          | -
    10     | Unused         | Yellow-Brown  | NO          | -


  Vici actuator controller pinout:
    Pin    | Function                      | Color         | Connected   | Active State
    -------|-------------------------------|---------------|-------------|---------------
    1      | Ground                        | Black         | YES - GND   | -
    2      | +5V VDC out                   | Brown         | NO          | -
    3      | Position A in                 | Red           | YES - A2    | HIGH
    4      | Position B in                 | Orange        | YES - A1    | HIGH
    5      | Position A out                | Yellow        | YES - 12    | HIGH
    6      | Position B out                | Green         | YES - 13    | HIGH
    7      | Position A relay contact out  | Blue          | NO          | -
    8      | Position B relay contact out  | Purple        | NO          | -
    9      | Position A relay contact in   | Grey          | NO          | -
    10     | Position B relay contact in   | N/A           | NO          | -


  OCB350 board pinout:
    Pin    | Function    | Color   | Connected
    -------|-------------|---------|-----------
    1      | VDC         | Red     | YES - 5V
    2      | Logic Out A | Orange  | YES - 9
    3      | Logic Out B | Blue    | YES - 10
    4      | Calibrate   | Green   | YES - 11
    5      | Analog Out  | White   | YES - A0
    6      | Ground      | Black   | YES - GND

 Libraries:
   no external libraries.

 Notes:
 -Pins
    Pins 0 and 1 not used as they are also used to transmit serial data.
 -Switch Valve
    Sample loop is filled from the (low pressure) reaction line in position A and then added to the (high pressure) HPLC line in position B
 -Phase Sensor
   Assumed calibration procedure: Place the tubing in the device with no liquid and then run the calibration (takes a second or so).
     pin A - HIGH &  pin B - LOW = Clear Solution
     pin A - LOW &  pin B - HIGH = Absorbing Solution
     pin A - HIGH &  pin B - HIGH = Gas/Empty
     pin A - LOW &  pin B - LOW = Error

  -Switch:
     2 - 1 - 6
     |       |
     |       |
     3 - 4 - 5
    1 = Input
    2 = Waste
    3 + 6 = Filling loop
    4 = To LCMS
    5 = From LCMS Pump

    Postion A (0) = 1+6 2+3 4+5
    Postion B (1) = 1+2 3+4 5+6
  
 Template by Simone Pilon <s.pilon at uva.nl> - Noël Research Group - 2024
 Functions by Olly Bayley <o.m.bayley at uva.nl> - Noël Research Group - 2024
*/

#include <math.h>
#include <EEPROM.h>
#include "Device_id.h"	// Routines to read and write device id.

// --Constants--
// LCMS Trigger Pins
#define START_REQUEST_SIGNAL_PIN 5 // Pin to output to ERI Remote Pin #1 (White)
#define STOP_SIGNAL_PIN 6 // Pin to output to ERI Remote Pin #2 (Brown)
#define READY_SIGNAL_PIN 7 // Pin to output to ERI Remote Pin #3 (Green)
#define POWER_ON_PIN 8 // Pin to output to ERI Remote Pin #4 (Grey)
#define EMERGENCY_SHUT_DOWN_PIN 9 // Pin to output to ERI Remote Pin #6 (Pink)
#define START_SIGNAL_PIN 10 // Pin to output to ERI Remote Pin #7 (Blue)
#define PREPARE_SIGNAL_PIN 11 // Pin to output to ERI Remote Pin #8 (Red)

// Phase Sensor Read Pins
#define PHASE_SENSOR_OUT_A_PIN 3 // Pin to read phase sensor output (Orange)
#define PHASE_SENSOR_OUT_B_PIN 4 // Pin to read phase sensor output (Blue)
#define PHASE_SENSOR_CALIBRATE_PIN 2 // Pin to calibrate phase sensor (Green)
#define PHASE_SENSOR_ANALOG_PIN 19 // Pin to read phase sensor output (White)

// Valve Control Pins
#define VALVE_A_IN_PIN 17  // Pin to to read valve position A (Vici Pin 3)
#define VALVE_B_IN_PIN 16 // Pin to to read valve position B (Vici Pin 4)
#define VALVE_A_OUT_PIN 15 // Pin to to set valve to position A (Vici Pin 5)
#define VALVE_B_OUT_PIN 14 // Pin to to set valve to position B (Vici Pin 6)

// Error codes (type)
#define ERROR_NO_ERROR 0	  // No error.
#define ERROR_SERIAL 1      // error value is variable number from error.
#define ERROR_PIN 2      	  // See pin.h

// EEPROM
#define EEPROM_ADDRESS_CHECK 0	// 1 byte char
#define DEFAULT_CHECK 42
#define EEPROM_ADDRESS_ID 1	// 20 bytes char[]
#define DEFAULT_ID "LCMS_Controller"

// --Global variables--
  // Error Handling
uint8_t error_type = 0;
uint8_t error_value = 0;
  //General
char good_acknowledge = 'k';
char bad_acknowledge = 'n';

//-----Action Methods-----
/**
 * Load stored values from EEPROM to system
 */
void load_defaults()
{
	uint8_t charvalue = 0;
	EEPROM.get(EEPROM_ADDRESS_CHECK, charvalue);
	if (charvalue == DEFAULT_CHECK)
	{
		eeprom_get_id(EEPROM_ADDRESS_ID);
	}
	else
	{
		factory_reset();
	}
}

/**
 * Store values from system to EEPROM as defaults
 */
void store_defaults()
{
	eeprom_put_id(EEPROM_ADDRESS_ID);
}

/**
 * Reset stored values to original defaults
 */
void factory_reset()
{
	uint8_t charvalue = DEFAULT_CHECK;
	EEPROM.put(EEPROM_ADDRESS_CHECK, charvalue);
	init_id(DEFAULT_ID);
	eeprom_put_id(EEPROM_ADDRESS_ID);
}

/**
 * Reads the Switch valve position based on the A and B pin logic. Defaults to 'error' state on bad read.
 */
int read_valve_pos(){
  int valve_position = 2;  //Error
  if (digitalRead(VALVE_A_IN_PIN) == LOW && digitalRead(VALVE_B_IN_PIN) == HIGH){
    valve_position = 0;  //A
  }else if (digitalRead(VALVE_A_IN_PIN) == HIGH && digitalRead(VALVE_B_IN_PIN) == LOW){
    valve_position = 1;  //B
  }
  return valve_position;
}

/**
 * Reads the phase sensor output. Defaults to 'error' state on bad read.
 */
int read_phase_sensor(){
  uint8_t state = 3;  //Error
  uint8_t phase_sensor_a_pin = digitalRead(PHASE_SENSOR_OUT_A_PIN);
  uint8_t phase_sensor_b_pin = digitalRead(PHASE_SENSOR_OUT_B_PIN);
  if(phase_sensor_a_pin == HIGH && phase_sensor_b_pin == LOW){
    state = 0; //Clear Solution
  }else if(phase_sensor_a_pin == LOW && phase_sensor_b_pin == HIGH){
    state = 1; //Absorbing Solution
  }else if(phase_sensor_a_pin == HIGH && phase_sensor_b_pin == HIGH){
    state = 2; //Empty
  }
  return state;
}

/**
 * Sets switch valve position based input. Defaults to 'bad acknowledge' if input is not 1 or 0.
 */
char set_valve_pos(int variable_value_int){
  if (variable_value_int == 0){ //Set position to A
    digitalWrite(VALVE_A_OUT_PIN, LOW);
    digitalWrite(VALVE_B_OUT_PIN, HIGH);
    return good_acknowledge;
  }
  else if (variable_value_int == 1){ //Set position to B
    digitalWrite(VALVE_A_OUT_PIN, HIGH);
    digitalWrite(VALVE_B_OUT_PIN, LOW);
    return good_acknowledge;
  } else{
     return bad_acknowledge;
  }
}

/**
 * Sends 'START REQUEST' to LCMS
 */
void start_analysis(){
  digitalWrite(START_REQUEST_SIGNAL_PIN, LOW); // Set to LOW (0V)
  delay(100);
  digitalWrite(START_REQUEST_SIGNAL_PIN, HIGH); // Return to HIGH (5V)
}

/**
 * Sends 'STOP' to LCMS
 */
void stop_analysis(){
  digitalWrite(STOP_SIGNAL_PIN, LOW); // Set to LOW (0V)
  delay(100);
  digitalWrite(STOP_SIGNAL_PIN, HIGH); // Return to HIGH (5V)
}

/**
 * Sends calibrate signal to phase sensor. Code assumes the PS is calibrated to an empty line.
 */
void calibrate_ps(){
  digitalWrite(PHASE_SENSOR_CALIBRATE_PIN, LOW); // Set to LOW (0V)
  delay(100);
  digitalWrite(PHASE_SENSOR_CALIBRATE_PIN, HIGH); // Return to HIGH (5V)
}


//-----Command Interpreter-----
/**
 * Checks serial line for commands and executes them.
 */
void parse_serial(){
	while (Serial.available() > 0){
		char command = Serial.read();
		int variable_number = 0;
    int int_response = 3;  // Default response is error

		if (command == 'R' || command == 'r'){  // Comands to READ and return info to caller
        // Read variable
        variable_number = Serial.parseInt();
        switch (variable_number){
        case 1:
            // Device identifier
            Serial.println(device_id);
            break;
        case 2:
            // Error register
            Serial.print(error_type);
            Serial.print('-');
            Serial.println(error_value);
            error_type = ERROR_NO_ERROR;
            error_value = 0;
            break;
        case 5:
          // Valve position
          int_response = read_valve_pos();
					Serial.println(int_response);
					break;
        case 6:
          // LCMS stop state
          int_response = digitalRead(START_REQUEST_SIGNAL_PIN);
          Serial.println(int_response);
        case 7:
          // LCMS stop state
          int_response = digitalRead(STOP_SIGNAL_PIN);
          Serial.println(int_response);
        case 8:
          // LCMS ready state
          int_response = digitalRead(READY_SIGNAL_PIN);
          Serial.println(int_response);
        break;
        case 10:
          // Phase sensor state
          int_response = read_phase_sensor();
          Serial.println(int_response);
        break;
				default:
					// Syntax errors
					error_type = ERROR_SERIAL;
					error_value = variable_number;
					break;
        case 11:
          // LCMS power state
          int_response = digitalRead(POWER_ON_PIN);
          Serial.println(int_response);
        break;
        case 12:
          // LCMS START Signal state
          int_response = digitalRead(START_SIGNAL_PIN);
          Serial.println(int_response);
        break;
        case 13:
          // LCMS PREPARE Signal state
          int_response = digitalRead(PREPARE_SIGNAL_PIN);
          Serial.println(int_response);
			}

		}
		else if (command == 'S' || command == 's'){  // Comands to SEND 
			// Write variable
			variable_number = Serial.parseInt();
			Serial.read();
			int variable_value_int = 0;
			float variable_value_float = 0;
      int step = 0;
      char variable_char_acknowledge = "n";
			// Write device-wide variable
			switch (variable_number){
				case 1:
					// Device identifier
					serial_read_id();
          Serial.println(good_acknowledge);
					break;
				case 3:
					// Save defaults
					store_defaults();
          Serial.println(good_acknowledge);
					break;
				case 4:
					// Factory reset
					factory_reset();
          Serial.println(good_acknowledge);
					break;
        case 5:
					// Set valve position
          variable_value_int = Serial.parseInt();
          variable_char_acknowledge = set_valve_pos(variable_value_int);
          Serial.println(variable_char_acknowledge);
					break;
        case 6:
          // Send START REQUEST through START_REQUEST_SIGNAL_PIN
          start_analysis();
          Serial.println(good_acknowledge);
          break;
        case 7:
          // Send STOP through STOP_SIGNAL_PIN
          stop_analysis();
          Serial.println(good_acknowledge);
          break;
        case 9:
          // Send Calibrate
          calibrate_ps();
          Serial.println(good_acknowledge);
          break;
				default:
					// Syntax error
					error_type = ERROR_SERIAL;
					error_value = variable_number;
					break;
          
			}

			// TODO you can check for errors and set the global variables here
			// if (Gpio_pin::error != GPIO_ERROR_OK)
			// {
			// 	error_type = ERROR_PIN;
			// 	error_value = Gpio_pin::error;
			// 	Gpio_pin::error = GPIO_ERROR_OK;
			// }
		}
	}
}

//-----Arduino Behaviour Methods-----

// This is run once when the Arduino is powered up.
void setup()
{
	// Load stored values from EEPROM
	load_defaults();

  // Initialize LCMS Trigger Pins
  // Read Pins
  pinMode(READY_SIGNAL_PIN, INPUT);
  pinMode(POWER_ON_PIN, INPUT);
  pinMode(START_SIGNAL_PIN, INPUT);
  pinMode(EMERGENCY_SHUT_DOWN_PIN, INPUT);
  pinMode(PREPARE_SIGNAL_PIN, INPUT);
  //Write Pins
  pinMode(START_REQUEST_SIGNAL_PIN, OUTPUT);
  digitalWrite(START_REQUEST_SIGNAL_PIN, HIGH);  // Set to LCMS defaults on startup to prevent triggering upon conection init
  pinMode(STOP_SIGNAL_PIN, OUTPUT);
  digitalWrite(STOP_SIGNAL_PIN, HIGH);           // Set to LCMS defaults on startup to prevent triggering upon conection init

  // Initialize Switch Pins
  // Read Pins
  pinMode(VALVE_A_IN_PIN, INPUT);
  int valve_a_current=digitalRead(VALVE_A_IN_PIN);
  pinMode(VALVE_B_IN_PIN, INPUT);
  int valve_b_current=digitalRead(VALVE_B_IN_PIN);
  // Write Pins
  pinMode(VALVE_A_OUT_PIN, OUTPUT);
  digitalWrite(VALVE_A_OUT_PIN, valve_a_current);  // Set valve to current position upon startup
  pinMode(VALVE_B_OUT_PIN, OUTPUT);
  digitalWrite(VALVE_B_OUT_PIN, valve_b_current); // Set valve to current position upon startup


  // Initialize Phase Sensor Pins
  pinMode(PHASE_SENSOR_OUT_A_PIN, INPUT);
  pinMode(PHASE_SENSOR_OUT_B_PIN, INPUT);
  // digitalWrite(PHASE_SENSOR_CALIBRATE_PIN, HIGH);
  // pinMode(PHASE_SENSOR_CALIBRATE_PIN, OUTPUT);
  // digitalWrite(PHASE_SENSOR_CALIBRATE_PIN, HIGH);
  
  //Read in current switch valve positionread();
  read_valve_pos();  // Ensure 

	// Initialize Serial interface
	Serial.begin(9600);
}

// This is run in a loop constantly during execution.
void loop()
{
	while (true)
	{
		parse_serial();
	}
}

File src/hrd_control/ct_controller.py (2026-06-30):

#!/usr/bin/env python3
# -*- coding: utf-8 -*-
"""
Author: O. Bayley
Description: Controls the behavior of the LCMS and switching system, allowing it to read data
and trigger complex behaviors. This script handles hardware communication, sensor monitoring,
and automation of the analysis cycle.
"""

import os
import logging
import time
import json
import serial.tools.list_ports
from typing import Any, Dict, Optional

from src.utils.get_project_path import get_project_path
from src.hrd_control.devices.lcms_device import LCMSDevice
from src.utils.custom_error_classes import *


class Controller:
    """
    The Controller class manages the LCMS device and associated hardware components.
    It initializes hardware connections, monitors sensors, and orchestrates the analysis cycle.
    """
    def __init__(self, hardware_settings) -> None:
        # Get hardware and timing settings
        self.hardware_settings: Dict[str, Any] = hardware_settings
        # Create LCMSDevice object
        self.lcms_device: LCMSDevice = self._init_device() # MockLCMSDevice()
        # Report initialization success
        self.log_info("Controller Object Initialized Successfully")

    # ----- Initialization Methods -----
    @staticmethod
    def _get_sensitive_settings() -> Dict[str, Any]:
        """
        Read the hardware settings JSON file and return all hardware settings.

        Returns:
            Dict[str, Any]: A dictionary containing the hardware settings.

        Raises:
            FileNotFoundError: If the settings file is not found.
            json.JSONDecodeError: If there is an error decoding the JSON.
            PermissionError: If there is a permission error accessing the file.
        """
        try:
            settings_path = os.path.join(get_project_path(), 'settings', 'protected_settings.json')
            with open(settings_path, 'r', encoding='utf-8') as settings_file:
                sensitive_settings = json.load(settings_file)
                logging.info("Loaded hardware settings successfully")
            return sensitive_settings
        except (FileNotFoundError, json.JSONDecodeError, PermissionError) as err:
            logging.error(f"Error occurred when loading hardware settings: {err}")
            raise

    def _init_device(self) -> LCMSDevice:
        """
        Initialize the LCMSDevice object by finding the correct serial port.

        Returns:
            LCMSDevice: An instance of the LCMSDevice class.

        Raises:
            ValueError: If no serial port is found for the device.
        """
        try:
            sensitive_settings = self._get_sensitive_settings()
            serial_num: str = sensitive_settings["arduino_serial_number"]
            device_port: Optional[str] = None
            ports = serial.tools.list_ports.comports()
            for port in ports:
                if port.serial_number == serial_num:
                    device_port = port.device
                    break

            if device_port is None:
                error_msg = f"No serial port found for the device: {serial_num}"
                logging.error(error_msg)
                raise ValueError(error_msg)

            baud_rate: int = self.hardware_settings.get("serial_baud_rate")
            timeout: float = self.hardware_settings.get("serial_timeout")
            logging.info(f"Initializing LCMSDevice on port {device_port} with baud rate {baud_rate}")
            return LCMSDevice(device_port, baud_rate, timeout)
        except Exception as err:
            logging.error(f"Failed to create LCMS Device due error: {err}")
            raise

    # ----- Analysis Method -----

    def run_sample_acquisition(self) -> str:
        """
        Run the routine to start an analytical run.
        This involves the detection, sample loading, and LCMS method triggering.

        Returns:
            str: 'SUCCESS' if the analysis cycle started successfully, 'FAIL' with an error message otherwise.
        """
        logging.info({'HPLC_analysis': 'INITIATED'})
        try:
            # Check devices are connected and in valid states. Raise error if not
            self._check_device_connectivity()
            self.log_info("Hardware connection check: SUCCESS")

            # Ensure that the switch is in the filling position when starting acquisition. i.e need sample in loop
            self._check_filling_state()
            self.log_info("Valve in filling position check: SUCCESS")

            # Attempt to send start request and wait for LCMS response
            attempt = 0
            max_attempts = 3
            self._send_start_request()
            # while attempt < max_attempts:
            #     attempt += 1  # Increment attempt counter
            #
            #     # Send start analysis and check acknowledgement
            #     self._send_start_request()
            #     self.log_info(f"Sending start signal: ATTEMPT {attempt}")
            #
            #     # Check request acknowledgement from spectrometer
            #     try:
            #         self._wait_on_lcms_response()
            #     except LCMSCommunicationError:
            #         self.log_info(f"Attempt {attempt} failed. LCMS did not acknowledge start request.")
            #         continue  # Try again
            #
            #     self.log_info("Start request acknowledged\nSample prep starting")
            #     break  # Exit loop if successful
            # else:
            #     error_msg = f"HPLC not starting after {max_attempts} attempts"
            #     logging.error(error_msg)
            #     raise LCMSCommunicationError(error_msg)

            time.sleep(0.3)

            # Wait for start signal/sample prep completion response from spectrometer
            self.log_info("Waiting on Start signal")
            self._wait_on_lcms_start()
            self.log_info("Aquisition Started")

            # Inject sample from the switch valve
            self.log_info("Setting valve to load position...")
            self.set_valve_to_pos(self.hardware_settings["valve_injection_position"])
            self.log_info("Valve set to load position: SUCCESS")

            # Sleep while emptying sample loop to prevent any accidental switching (Safety precaution)
            flush_time = self.hardware_settings["sample_loop_flush_time"]
            self.log_info(f"Waiting {flush_time}s to flush out the sample loop")
            time.sleep(flush_time)
            self.log_info("Sample loading complete")

            # Report triggering success
            self.log_info("Analysis cycle started successfully")

            return 'SUCCESS'

        except ControllerError as error:
            logging.error(f"Analysis cycle FAILED: {error}")
            raise

    # ----- Compound Command Methods -----

    def _check_device_connectivity(self) -> None:
        """
        Check that the Arduino microcontroller, switch valve, phase sensor, and LCMS are connected.
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

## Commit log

2024-05-03 updated the server security
    no longer take a user but rather all allowed devices are whitelisted by the server
2024-05-07 commented out auto server socket closure
2024-06-06 updated Arduino code for new box
2024-06-26 updated threaded logging and .json log result file
2024-07-11 runlog to summary and reducing threaded info
2024-07-15 arduino_monitor updates
2024-07-15 shifted ard_mon prints
2024-07-24 updates to hardware side, particularly the phase sensor
2024-07-24 adding a simple chromatogram analyser that does not require calibration data
2024-07-24 Updated all ct programs logging/printing for clarity. Updated the result dir identification
2024-07-24 cleaning print outputs
2024-07-24 Updated ct_controller to be able to stop the phase sensor monitoring
2024-07-25 Simple analyser now picks and deconvolutes all peaks without the need for calibration
2024-08-06 Updated Analyser
    [Calibration_data.csv, output.csv]
2024-10-22 Code cleaning - adding docstrings, enforcing types with type hints, improving logging, adding custom errors and catching
    [ct_controller.py]
2024-10-24 code cleaning, adding docstrings and type hints, redoing the RunLog to be less specific on inputs. Making the parameter selection more controlled by robochem (to improve ominiplat compatability). Mak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
2024-11-27 updates for Omni integration
    [test.csv]
2025-01-27 added ability to analyser to have a reference UV spectra for spectral matching
    [spectrum_10_rt_6.429.csv, spectrum_11_rt_6.666.csv, spectrum_1_rt_2.111.csv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]
2025-01-28 added ref spectra for testing and added more similarity matching algorithms
    [spectrum_10_rt_6.429.csv, spectrum_11_rt_6.666.csv, spectrum_1_rt_2.111.csv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]
2025-01-28 tidying updates
    [0.899.csv, 0.978.csv, 2.012.csv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]
2025-08-19 logging and usage changes
    [eChem_Reductive_Product.csv, product.csv]
2025-08-25 cleaning updates
    [Calibration_data.csv, LC_ENC.stl, LC_ENCL.stl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]
2025-10-09 moved dir structuring
    [LC_ENC.stl, LC_ENCL.stl, LED_clamp.stl]
